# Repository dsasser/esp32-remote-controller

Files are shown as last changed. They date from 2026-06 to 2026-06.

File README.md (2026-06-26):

# ESP32-S3 4-Channel Remote Igniter Controller

A portable, wireless 4-channel remote igniter controller for **hobby rocketry**. Fires up to four Estes-type igniters independently over BLE from a phone. Single 2S Li-ion battery, ESP32-S3 Super Mini, in a Hammond 1455N1601BK anodized aluminum enclosure with custom SendCutSend panels.

> **Status:** Hardware design finalized (2S single-battery). Firmware in active development.

Assembled controller

Schematic

---

## Features

- 4 independently fired channels for hobby igniters
- 7.4V raw cell voltage fires Estes igniters directly (0.5-1A typical)
- BLE 5.0 control via phone (WiFi / ESP-NOW options in firmware)
- Single 2S pack: 2x Samsung 30Q 18650 + 2S BMS
- One MP1584EN buck (7.4V -> 5V) for ESP32 and relay logic
- VNFOCKQSH optocoupler-isolated relay, mounted off-board
- TVS diode protection per channel; inline 5A fuse on the 7.4V rail
- Master power switch (SW1) cuts battery+ to the whole device
- 8.4V barrel-jack charging through the BMS (works with the switch off)
- Hammond aluminum enclosure with custom SendCutSend panels
- Socketed ESP32 and off-board relay — fully serviceable

---

## Quick Start

1. Order parts from the [Bill of Materials](docs/02-bom.md)
2. Review the [Schematic](docs/03-schematic.md)
3. Build following the [Assembly Guide](docs/07-assembly.md)
4. Flash firmware from the [Firmware Guide](docs/06-firmware.md)
5. Panels are pre-cut from the DXF files in [`/hardware`](hardware)

---

## Repository Structure

```
remote-controller/
├── README.md
├── LICENSE                    CERN-OHL-P (hardware) + MIT (firmware)
├── docs/
│   ├── 01-overview.md         Architecture, design decisions, specs
│   ├── 02-bom.md              Full bill of materials
│   ├── 03-schematic.md        Schematic + wiring (see images/schematic.svg)
│   ├── 04-pcb-layout.md       ElectroCookie breadboard-node placement
│   ├── 05-enclosure.md        Hammond enclosure + panel compatibility
│   ├── 06-firmware.md         BLE firmware, flashing, testing
│   ├── 07-assembly.md         Stage-by-stage build
│   └── images/
│       ├── schematic.svg          Block / interconnect schematic
│       ├── schematic-detail.svg   Component-level engineering schematic
│       ├── assembled.svg          Assembled three-quarter render
│       ├── parts-breakout.svg     Labelled parts breakout
│       ├── front-panel.svg        True-to-scale front panel elevation
│       └── rear-panel.svg         True-to-scale rear panel elevation
├── hardware/
│   ├── front_panel.dxf        Binding posts + LED (2D, aluminum)
│   ├── rear_panel.dxf         Power switch + charge jack + USB-C (2D, aluminum)
│   ├── front_panel.step/.stl  3D-print solid (Fusion / slicer)
│   ├── rear_panel.step/.stl   3D-print solid (Fusion / slicer)
│   └── generate_panels.py     Parametric source (CadQuery → STEP/STL)
└── firmware/
    └── remote_controller/
        └── remote_controller.ino
```

---

## Architecture at a Glance

```
[2S Pack 7.4V] -> [BMS] -> [SW1] -+-> [5A fuse] -> relay COM x4 -> NO -> [TVS] -> posts -> igniters
                                  |
                                  +-> [MP1584EN 5V] -> ESP32-S3 + relay logic
                                                |
                                          BLE <- phone
```

---

## Drawings & Renders

| Drawing | Description |
|---|---|
| [Assembled render](docs/images/assembled.svg) | Three-quarter view of the finished controller |
| [Parts breakout](docs/images/parts-breakout.svg) | Every component, grouped by function |
| [Component schematic](docs/images/schematic-detail.svg) | Net-level schematic for build / debug |
| [Front panel](docs/images/front-panel.svg) · [Rear panel](docs/images/rear-panel.svg) | True-to-scale elevations generated from the `/hardware` DXFs |
| [Internal layout](docs/images/internal-layout.svg) · [Side view](docs/images/internal-side.svg) | Top-down placement + connections, and heights/clearance |
| [PCB placement](docs/images/pcb-placement.svg) | Component placement on the ElectroCookie breadboard nodes |

---

## License

Hardware & docs: **CERN-OHL-P v2**. Firmware: **MIT**. See [LICENSE](LICENSE).

---

## Contributing

Issues and PRs welcome. If you build one, share photos — open an issue tagged `build-log`.

---

## Safety

This device fires pyrotechnic igniters. Relays default open at power-up; the firmware fires momentary pulses only. Follow NAR/Tripoli safety guidelines and maintain safe distance.

---

## Acknowledgements

Designed with assistance from Claude (Anthropic).

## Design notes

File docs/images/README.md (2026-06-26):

# Images

| File | What it is |
|---|---|
| `schematic.svg` | Block / interconnect schematic (2S single-battery) |
| `schematic-detail.svg` | Component-level engineering schematic — symbols, pins, rails, decoupling, per-channel TVS |
| `assembled.svg` | Three-quarter render of the finished controller |
| `parts-breakout.svg` | Every component, grouped by function with ref designators |
| `front-panel.svg` | True-to-scale front panel elevation (generated from `hardware/front_panel.dxf`) |
| `rear-panel.svg` | True-to-scale rear panel elevation (generated from `hardware/rear_panel.dxf`) |
| `internal-layout.svg` | Top-down floor plan — board/battery placement, connections, wire gauges |
| `internal-side.svg` | Side view — component heights, lid clearance, wire-gauge table |
| `pcb-placement.svg` | PCB component placement on the ElectroCookie breadboard nodes |

The two panel elevations are generated from the DXF source; if the DXFs change, regenerate rather than hand-editing the SVG.

Add build photos here as the hardware comes together.

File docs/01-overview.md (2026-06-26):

# 01 — System Overview

## What This Is

A portable 4-channel remote igniter controller for **hobby rocketry**. It fires up to four Estes-type igniters wirelessly over BLE from a phone, delivering a momentary firing pulse to each channel independently. Built around the ESP32-S3 Super Mini in a Hammond 1455N1601BK anodized aluminum enclosure with custom SendCutSend panels.

---

## Design Goals

| Goal | How it's met |
|---|---|
| Portable and self-contained | Single internal 2S battery, no external power |
| Wireless control | ESP32-S3 BLE 5.0, ~30-100ft range |
| Safe firing | Relays default open, optocoupler isolation, TVS protection |
| Simple | One battery, one buck converter, minimal parts |
| Serviceable | Socketed ESP32, off-board relay, replaceable inline fuse |
| Professional finish | Hammond aluminum enclosure, SendCutSend panels |

---

## System Architecture

A single **2S Li-ion pack** (2× Samsung 30Q in series, 7.4V nominal) powers everything:

- **Firing power:** Raw 7.4V routes through the master switch (SW1) and a 5A fuse to the relay COM terminals. When a relay fires, 7.4V appears across the binding posts and fires the igniter. Estes igniters need only 0.5-1A, so 7.4V is entirely sufficient. With SW1 off, the COM bus and posts are dead.
- **Logic power:** One MP1584EN buck converter steps 7.4V down to a regulated 5.0V, powering both the ESP32-S3 and the relay module's coil/logic side.

This single-battery design replaced an earlier, more complex dual-battery architecture. The simplification was possible because hobby igniters are forgiving, low-current loads.

```
[Phone / BLE]
      | BLE
      v
[ESP32-S3 Super Mini] --GPIO4-7 via 6-wire ribbon--> [VNFOCKQSH Relay (off-board)]
      ^                                                      |
[MP1584EN 5V buck]                                      COM x4 <-- 7.4V (switched, fused)
      ^                                                NO x4
[SW1 master power switch]                                   |
      ^                                              [TVS D2-D5] + [Binding Posts]
[2S Pack: 2x Samsung 30Q] -> [2S BMS] <-- 8.4V charger      |
                                                      [Igniters 1-4]
```

---

## Key Design Decisions

**Why 2S 18650 instead of a 12V pack?**
Estes igniters fire at 0.5-1A. The raw 7.4V from two series cells drives them directly — no need for a 12V switching supply or a separate logic battery. Two cells, one BMS, one buck converter. Lighter and simpler.

**Why the VNFOCKQSH relay module?**
Cheaper and faster-shipping than the original pick, with optocoupler isolation and a selectable H/L trigger jumper. The optocouplers protect the ESP32 GPIOs; the relay contacts handle output isolation. The JD-VCC jumper is removed.

**Why mount the relay off-board?**
Keeps the ElectroCookie PCB compact and uncluttered. The relay bolts to the Hammond's internal floor via M3 screws and connects back to the board with a 6-wire ribbon (GND, 5V, IN1-4). Easy to replace.

**Why BLE?**
No infrastructure needed — works anywhere at the launch site. Pairs in under a second. The firmware also has WiFi and ESP-NOW options roughed in.

---

## Specifications

| Parameter | Value |
|---|---|
| Output channels | 4 |
| Output voltage | 7.4V (raw 2S cell voltage) |
| Igniter load | 0.5-1A typical (Estes-type) |
| Pulse duration | Configurable, default 1000ms |
| Wireless | BLE 5.0 (primary), WiFi / ESP-NOW (optional) |
| Battery | 2S — 2x Samsung 30Q 18650, 7.4V ~3000mAh |
| BMS | 2S Li-ion protection, 10A+ |
| Charging | 8.4V wall charger via DaierTek barrel jack |
| Output connectors | 4mm banana binding posts, 4 pairs |
| Enclosure | Hammond 1455N1601BK, 160x103x53mm |
| Microcontroller | ESP32-S3 Super Mini |
| Relay | VNFOCKQSH 5V 4-channel, optocoupler isolated |
| Protection | TVS diodes, optocoupler isolation, 5A fuse, 2S BMS |

---

## Safety Notes

This device fires pyrotechnic igniters. Observe standard rocketry safety:

- Relays default to open (safe) on power-up
- Keep the system unpowered until ready to fire
- Maintain safe distance per NAR/Tripoli guidelines
- The momentary-pulse firmware prevents a stuck-on output
- TVS diodes clamp inductive spikes from the igniter bridgewire

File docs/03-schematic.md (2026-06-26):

# 03 — Schematic

Schematic

The block-level schematic above (`docs/images/schematic.svg`) documents interconnection between the modules.

For a net-level view an electronics engineer can build and debug from — proper symbols, pin names, power rails, decoupling, per-channel TVS and binding posts — see the component schematic:

Component schematic

---

## Power Architecture

A single 2S pack feeds two paths:

```
[2S Pack: 2x Samsung 30Q in series, 7.4V]
        |
   [2S BMS] <--- 8.4V charger (DaierTek barrel jack J1)
        |
   [SW1 master power]  --lamp--> GND   (illuminated rocker, rear panel)
        |
   [F1 5A inline fuse]
        |
   7.4V BUS ----+---------------------------+
        |       |                           |
        |   relay COM x4              [MP1584EN U1]
        |                             7.4V -> 5.0V
        |                                   |
        |                              5V BUS
        |                                   |
        |                          +--------+--------+
        |                       [ESP32-S3]      [Relay VCC]
        v
   relay NO x4 --> [TVS D2-D5] --> [Binding posts] --> igniters
```

GND is common across the whole system. **SW1 sits between the BMS and the
7.4V bus**, so when it's off the ESP32, the buck, and the firing rail (relay
COM and the binding posts) are all de-energized. The charger feeds the BMS
*upstream* of SW1, so the pack still charges with the device switched off.

---

## Designators

| Ref | Component |
|-----|---|
| B1 | 2S pack — 2x Samsung 30Q 18650 in series (7.4V) |
| — | 2S Li-ion BMS protection board |
| J1 | DaierTek 5.5x2.1mm barrel jack (charge port) |
| SW1 | Master power rocker switch (illuminated, ∅12mm panel-mount) |
| F1 | 5A blade fuse + inline holder (internal) |
| U1 | MP1584EN buck converter (7.4V -> 5.0V) |
| U2 | ESP32-S3 Super Mini |
| K1 | VNFOCKQSH 4-channel relay module (off-board) |
| D1 | 5mm green LED (status) |
| R1 | 330Ω ¼W resistor |
| D2-D5 | P6KE15A TVS diodes (one per channel) |
| C1 | 100µF 25V electrolytic (5V decoupling) |
| C2-C5 | 0.1µF ceramic (relay IN decoupling) |
| BT1-BT4 | 4mm banana binding post pairs |

---

## GPIO Assignments

| GPIO | Function |
|---|---|
| GPIO4 | Relay IN1 (Channel 1) |
| GPIO5 | Relay IN2 (Channel 2) |
| GPIO6 | Relay IN3 (Channel 3) |
| GPIO7 | Relay IN4 (Channel 4) |
| GPIO2 | Status LED (via R1) |

---

## Relay Connection (6-wire ribbon)

The relay module mounts off-board on the enclosure floor. A 6-conductor ribbon connects it to screw terminals on the PCB:

| Ribbon wire | From (PCB) | To (relay) |
|---|---|---|
| 1 | GND bus | GND |
| 2 | 5V bus | VCC |
| 3 | GPIO4 | IN1 |
| 4 | GPIO5 | IN2 |
| 5 | GPIO6 | IN3 |
| 6 | GPIO7 | IN4 |

Relay COM terminals connect to the fused 7.4V bus. Relay NO terminals go to the TVS diodes and binding posts.

---

## Critical Notes

### MP1584EN pre-adjustment
Before connecting the ESP32 or relay, power the MP1584EN from the pack and adjust its trimmer pot until the output reads **5.00V ± 0.05V**. The pot is sensitive — use a small flat screwdriver and turn slowly. Over-voltage damages the ESP32-S3.

### Relay jumpers
- **JD-VCC jumper: removed.** The optocouplers already isolate the ESP32 GPIOs; output isolation is handled by the relay contacts.
- **H/L trigger jumper: set to match firmware.** The VNFOCKQSH has a selectable high/low trigger. Set it to match the firmware's `RELAY_ACTIVE_LOW` setting (default active-LOW).

### TVS orientation
P6KE15A is unidirectional. The **cathode (stripe end)** faces the positive binding post. Reversed orientation shorts the output.

### Master switch (SW1) & lamp
SW1 carries the full battery+ current (logic plus firing — a few amps peak), so use a switch rated comfortably above that; the linked rocker is rated well beyond. Wire the two contact leads in series with battery+ (BMS out → SW1 → F1). The two lamp leads are a separate illuminated indicator: lamp+ to the switched 7.4V (downstream of SW1), lamp− to GND, so it glows when the device is on. **If the lamp is rated 12V it will be dim or dark at 7.4V** — the switching itself is unaffected; for a bright indicator either source the lamp from a 12V supply or rely on the front status LED.

### Wire gauge
- 18 AWG for all 7.4V power (battery, switch, fuse, COM, output)
- 22 AWG for 5V logic and GPIO ribbon

---

## Why 7.4V Is Enough

Estes igniters fire at 0.5-1A. At 7.4V through a low-resistance bridgewire, the available current far exceeds the firing threshold. There is no benefit to a higher switching voltage for this load, which is what allowed the design to collapse from two batteries to one.

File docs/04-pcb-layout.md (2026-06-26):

# 04 — PCB Layout

The build uses a **black ElectroCookie solderable breadboard**. The medium (~80×60mm, 30-column) board is enough — the layout below uses only ~22 of its 30 columns — but a larger ElectroCookie also fits the enclosure if you want more elbow room. The relay module mounts **off-board** on the enclosure floor, so the PCB only carries the ESP32, buck, decoupling, the TVS/output section, and the screw terminals.

PCB placement on the breadboard nodes

---

## Work with the copper, not against it

The ElectroCookie is a 1:1 breadboard replica, so component placement follows breadboard rules — it is **not** free-form:

- **Node strips:** the main field is two banks split by a **center gap**. Each vertical group of **5 holes is one electrical node** (one trace). Adjacent groups are isolated.
- **Power rails:** continuous bus strips run along the two **long edges**. Dedicate one rail to **+5V** and the other to **GND**. (If your board has a second rail per side, give the spare to **+7.4V** and skip the jumper below.)

The consequence: a part with two rows of pins (notably the ESP32-S3) **straddles the center gap**, so each pin lands on its own 5-hole node with four free holes for jumpers — exactly like seating a DIP on a breadboard. Small single-row modules (the MP1584EN) just sit in one bank, each pad on its own node.

---

## Placement

### Power rails (long edges)
- Top edge → **+5V** bus. Bottom edge → **GND** bus.
- Jumper each part's 5V and GND pins straight to the nearest rail.
- **7.4V** has no dedicated rail on a 2-rail board: bring it in on a screw terminal and jumper it to the MP1584EN input and the relay-COM feed. (Or use a 3rd/4th rail if your board has one.)

### MP1584EN buck — input end
- Each pad on its own node. **IN+** from the 7.4V terminal, **IN−/OUT−** to the GND rail, **OUT+** jumpered to the +5V rail.
- **Mount and trim to 5.00V before anything else is connected.** The pot is sensitive.

### ESP32-S3 Super Mini — center, straddling the gap
- On two rows of **8-pin female 2.54mm headers** (the Super Mini is narrow). Socketed so it lifts out.
- 5V pin → +5V rail; GND → GND rail.
- **GPIO4–7** jumper to the relay-signal screw terminal (the 6-wire ribbon). **GPIO2 → R1 →** a ~15cm flying lead to the panel status LED.

### TVS + outputs — output end
- Per channel: the **relay NO** wire lands on a node; a **TVS diode (D2–D5)** bridges that node to the **GND rail**, cathode (stripe) toward the **+** output; an output screw terminal taps the same node out to the binding post **+**. Each post **−** returns to the GND rail.

### Decoupling
- **C1** (100µF) across +5V↔GND near the ESP32. **C2–C5** (0.1µF) at the relay IN terminals.

---

## Wire gauge

| Run | Gauge |
|-----|---|
| 7.4V firing path (battery, fuse, SW1, relay COM, NO → posts) | **18 AWG** |
| 6-wire ribbon to the relay (GND, 5V, IN1–IN4) | 18–22 AWG (logic/signal only, <0.4A) |
| 5V / GPIO logic, status-LED lead | 22–26 AWG |

Keep the 7.4V runs on one side of the board and 5V/signal on the other where you can, for noise isolation.

---

## Internal mounting

```
Hammond 1455N1601BK floor (single layer, ~20mm-tall parts, ~25mm headroom):
  - ElectroCookie PCB on M3 standoffs (front)
  - VNFOCKQSH relay module bolted flat to the floor, M3 (rear)
  - 2S 18650 pack lying down, hook-and-loop strap
  - 2S BMS + inline 5A fuse tucked beside the battery
  - SW1, barrel jack, USB-C on the rear panel; binding posts + LED on the front
```

See [07-assembly.md](07-assembly.md) for the top-down layout and side-view height drawings. The off-board relay and single battery leave plenty of room; the 6-wire ribbon has enough slack to lift the PCB out without unplugging the relay.

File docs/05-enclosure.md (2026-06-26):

# 05 — Enclosure

## Hammond 1455N1601BK

**External:** 160mm L x 103mm W x 53mm H
**Internal usable depth:** ~45mm
**Material:** Extruded aluminum, black anodized, IP54
**End panels:** Removable aluminum, 103 x 53mm each

Front and rear panels are custom-cut by **SendCutSend** from the DXF files in `/hardware`.

---

## Revision after first fabrication

The first set of panels came back from SendCutSend with three fit problems against the real parts:

1. **Binding-post nuts collided.** The two posts in each pair were only 10mm apart center-to-center; the mounting nuts/washers overlap and can't both seat.
2. **Fuse slot was unusable.** The 20×13mm slot assumed a panel-mount blade fuse holder, but the fuse in the BOM is an **inline pigtail holder** that has no flange or thread to mount through a panel at all.
3. **USB-C opening was too small.** The 9×3.5mm slot fit only a bare USB-C *plug*, not a panel-mount USB-C *receptacle*. It's now a **∅11.5mm round hole** for an M11×1.0 threaded receptacle (J2) whose nut clamps any panel thickness.

The DXFs in `/hardware` are the **corrected revision**:

| Panel feature | Size | Resolution |
|---|---|---|
| Front: 8× ∅8mm holes | 8mm | Binding posts re-laid as a **2-row grid** (4 columns @ 22mm pitch, +/− rows 20mm apart) so nuts clear — min 20mm center-to-center |
| Front: ∅5mm hole | 5mm | Status LED — moved to the right edge, vertically centered |
| Rear: ∅12mm round hole | 12mm | DaierTek barrel jack — unchanged, correct size |
| Rear: ~~20×13mm fuse slot~~ | — | **Removed.** Inline fuse holder now lives inside the enclosure |
| Rear: ∅12mm round hole | 12mm | **Master power switch (SW1)** restored — see note below |
| Rear: USB-C cutout | **∅11.5mm round** | M11×1.0 threaded panel-mount USB-C, nut-clamped (was 9×3.5mm) |
| Both: 4× ∅3mm corner holes | 3mm | M3 panel mounting — unchanged |

> The rear USB-C receptacle preserves wired firmware flashing and serial debug access to the ESP32-S3 Super Mini. It's an **M11×1.0 threaded mount**: the barrel passes through the ∅11.5mm hole and a hex nut clamps from behind, so it seats solidly in panels of any thickness. Its 4-wire pigtail plugs into the ESP's USB pads internally.

> **Master power switch (SW1) restored.** The original design had a panel master switch, but it was lost when the design consolidated to 2S — its rear slot was relabeled as the fuse cutout and then removed. It's back as a **∅12mm round hole at X=22mm**, giving a symmetric POWER / CHARGE / USB-C layout. A master cutoff is *more* important in the 2S design: the pack feeds the buck continuously, so without it the ESP32 is always drawing current, and switching it off de-energizes the firing rail (the binding posts go dead). See [03-schematic.md](03-schematic.md).

> The 5A fuse is now an **inline holder wired into the battery+ lead inside the box** (see [02-bom.md](02-bom.md)). The rear panel carries no fuse cutout. To restore panel-accessible fuse swaps, switch to a round-bezel panel-mount holder and add a ∅12mm hole to `rear_panel.dxf`.

---

## Panel Elevations

These elevations are generated directly from the `/hardware` DXF coordinates, so they are true to scale (1:1 in mm). `CUT` features are red, `ENGRAVE` labels blue, dimensions gray.

**Front panel** — 4 binding-post pairs (CH1–CH4) in a 2-row grid, status LED, 4× M3 corner holes:

Front panel elevation

**Rear panel** — power switch, charge jack, USB-C cutout, 4× M3 corner holes (no fuse slot):

Rear panel elevation

---

## Front Panel Hole Positions

Posts sit in two rows: **+ (red) at Y = 36.5mm**, **– (black) at Y = 16.5mm**. Each channel is one column.

| Channel | Hole | Column X | + row Y | – row Y |
|---|---|---|---|---|
| CH1 | ∅8mm | 18.5mm | 36.5mm | 16.5mm |
| CH2 | ∅8mm | 40.5mm | 36.5mm | 16.5mm |
| CH3 | ∅8mm | 62.5mm | 36.5mm | 16.5mm |
| CH4 | ∅8mm | 84.5mm | 36.5mm | 16.5mm |
| Status LED | ∅5mm | 94.0mm | — (Y = 26.5mm) | |

Column pitch: 22mm. Row spacing (+ to –): 20mm. Minimum nut clearance: 20mm center-to-center.

## Rear Panel Hole Positions (Y = 26.5mm center)

| Feature | Hole | X position |
|---|---|---|
| Power switch SW1 | ∅12mm | 22mm |
| Charge jack J1 | ∅12mm | 52mm |
| USB-C (J2, flashing) | ∅11.5mm round (M11 threaded mount) | 87mm |

---

## Fabrication Files

The panels can be **laser/waterjet cut from aluminum** (2D DXF) or **3D printed** (3D STEP/STL solids). Both come from one shared geometry definition, so the hole positions match.

**DXF (aluminum)** — `/hardware/front_panel.dxf` and `/hardware/rear_panel.dxf` carry *nominal* hole sizes across five layers:
- `CUT` (red) — holes and slots
- `ENGRAVE` (blue) — labels
- `OUTLINE` (black) — panel boundary, reference only
- `DIMENSION` (gray) — measurements, reference only
- `CENTERLINE` (green, dashed) — hole crosshairs, reference only

These import directly into SendCutSend, Front Panel Express, or any CAD/CAM tool.

**STEP / STL (3D print)** — `/hardware/front_panel.step` and `/hardware/rear_panel.step` are the panels as **solid bodies** with PETG-compensated holes and debossed labels. In **Autodesk Fusion**, bring the STEP in via **File → Open** (or upload it to the project) — it lands as a native, editable solid you can tweak with push/pull. The matching `.stl` files (`Insert → Insert Mesh`, or straight into a slicer) are ready to print as-is.

> **Changing thickness:** the solids are built by `/hardware/generate_panels.py` (CadQuery). Edit `THICKNESS` at the top and re-run (`pip install cadquery && python hardware/generate_panels.py`) to regenerate both STEP + STL. That script is the parametric source — easier than push/pulling the body in Fusion, though either works.

---

## 3D-Printed Panels

The STEP/STL solids default to a **2mm** panel. Pick thickness by how the panel attaches:

- **~1.5mm** to slide into the Hammond extrusion's grooves (matches the stock aluminum panel).
- **2–3mm** for a stiffer panel bolted on through the four M3 corner holes.

> Every panel-mount part here clamps with a nut or threaded body — binding posts, the rocker switch (SW1), barrel jack, and the **M11×1.0 threaded USB-C** (J2). They all seat in any printed thickness, so there's no thin-wall snap-fit to design around. The USB-C thread is ~14.5mm long, plenty for a 2–3mm panel.

### Hole tolerances

Baked into the STEP/STL solids for black PETG on a 0.4mm nozzle. If your printer runs tight, bump the radii in `generate_panels.py` and re-run.

| Feature | Nominal | Printed |
|---|---|---|
| M3 corner hole | ∅3.0mm | ∅3.2mm |
| Binding post | ∅8.0mm | ∅8.4mm |
| Status LED | ∅5.0mm | ∅5.2mm |
| Power switch / barrel jack | ∅12.0mm | ∅12.4mm |
| USB-C (M11 thread) | ∅11.5mm | ∅11.9mm |

### Print settings

| Setting | Value |
|---|---|
| Material | Black PETG |
| Layer height | 0.15mm |
| Infill | 40% |
| Orientation | Front (labeled) face down — best surface on the visible side |

---

## Panel Labeling

For now a label maker works fine. For a professional finish, the DXF `ENGRAVE` layer can be sent to SendCutSend (engraving) or Front Panel Express for laser-engraved, anodized labels.

Suggested labels: CH1-CH4 above each binding-post column, "CHARGE" by the barrel jack, "USB-C" by the rear USB cutout, polarity + / - marks per post. (The fuse is internal, so it needs no panel label.)

---

## Internal Mounting

- **PCB:** M3 standoffs to the floor, or slide into the enclosure's internal rails
- **Relay module:** bolted flat to the floor via M3 through its corner holes
- **2S pack:** hook-and-loop strap to the floor so it can't shift
- **Inline fuse holder:** wired into the battery+ lead and tucked inside the box (zip-tied to the floor or harness); open the enclosure to swap the fuse
- **Barrel jack + USB-C receptacle:** panel-mounted on the rear, wired with enough slack to swing the panel open ~45 deg for servicing

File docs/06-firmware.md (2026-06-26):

# 06 — Firmware

## Overview

The firmware runs on the ESP32-S3 Super Mini using the Arduino ESP32 core. It exposes a BLE GATT service with a single writable characteristic. Writing the values `"1"` through `"4"` fires the corresponding channel for the configured pulse duration.

The complete firmware source is in `/firmware/remote_controller/remote_controller.ino`.

---

## Development Environment Setup

### 1. Install Arduino IDE

Download from [arduino.cc/en/software](https://www.arduino.cc/en/software). Version 2.x recommended.

### 2. Add ESP32 Board Support

In Arduino IDE: **File → Preferences → Additional boards manager URLs**, add:

```
https://raw.githubusercontent.com/espressif/arduino-esp32/gh-pages/package_esp32_index.json
```

Then: **Tools → Board → Boards Manager**, search `esp32`, install **esp32 by Espressif Systems** (version 3.x recommended).

### 3. Select Board

**Tools → Board → ESP32 Arduino → ESP32S3 Dev Module**

Settings:
- USB Mode: **USB-OTG (TinyUSB)**
- Upload Mode: **UART0 / Hardware CDC**
- Flash Size: **4MB**
- Partition Scheme: **Default 4MB with spiffs**

### 4. Select Port

Plug the ESP32-S3 Super Mini in via USB-C. If no port appears, hold the BOOT button while plugging in. Select the corresponding port under **Tools → Port**.

---

## Flashing

With the board selected and port set, open `/firmware/remote_controller/remote_controller.ino` and click **Upload** (→ arrow). The IDE compiles and flashes. The status LED will blink 3 times then hold solid when BLE is advertising.

If the upload fails: hold BOOT on the ESP32-S3, press and release RESET, then release BOOT. This forces download mode.

---

## BLE Protocol

| Property | Value |
|---|---|
| Device name | `RemoteBox` |
| Service UUID | `4fafc201-1fb5-459e-8fcc-c5c9c331914b` |
| Characteristic UUID | `beb5483e-36e1-4688-b7f5-ea07361b26a8` |
| Characteristic property | WRITE |

### Commands

Write a single ASCII character to the characteristic:

| Value | Action |
|---|---|
| `"1"` | Fire channel 1 |
| `"2"` | Fire channel 2 |
| `"3"` | Fire channel 3 |
| `"4"` | Fire channel 4 |
| `"A"` | Fire all channels simultaneously |
| `"S"` | Status query (returns `"OK"` if connected) |

### Testing Without an App

Use **nRF Connect** (iOS / Android — free):

1. Open nRF Connect, tap **SCAN**
2. Find `RemoteBox` in the list, tap **CONNECT**
3. Navigate to the service UUID, expand the characteristic
4. Tap the **↑ Upload** icon to write
5. Type `1`, `2`, `3`, or `4`, tap **SEND**
6. You should hear the relay click

---

## LED Status Codes

| Pattern | Meaning |
|---|---|
| 3 blinks, then solid ON | BLE advertising, ready |
| Solid ON | BLE connected |
| OFF | Not powered / error |
| Fast blink (100ms) | Firing in progress |

---

## Configuration

At the top of `remote_controller.ino`, adjust these defines to customize behavior:

```cpp
// GPIO assignments — match your wiring
#define CH1_PIN   4
#define CH2_PIN   5
#define CH3_PIN   6
#define CH4_PIN   7
#define LED_PIN   2

// Pulse duration in milliseconds
#define FIRE_MS   1000

// BLE device name (appears in phone scan list)
#define BLE_NAME  "RemoteBox"

// Active LOW relay logic (true for most prebuilt relay modules)
// Set to false if your relay fires on HIGH.
// Match the VNFOCKQSH H/L trigger jumper to this setting.
#define RELAY_ACTIVE_LOW  true
```

---

## WiFi Alternative

If you prefer WiFi control over BLE, a web server approach is straightforward with the ESP32 Arduino core. The ESP32-S3 can host its own access point — no router needed. See the commented-out WiFi section at the bottom of the firmware file for a starting point.

WiFi adds ~1–2 seconds of connection time vs BLE's near-instant connection, but gives you a browser-based UI on any device.

---

## ESP-NOW Option (future)

For a dedicated physical button controller (a second ESP32-S3 as a handset), ESP-NOW provides:

- No pairing or handshake — just power on and it works
- Sub-10ms latency
- ~200m range
- Works without any phone

See the `firmware/esp_now_controller/` directory (planned — contributions welcome).

---

## Troubleshooting

| Problem | Likely cause | Fix |
|---|---|-----|
| Relay clicks but igniter doesn't fire | Pack low or 5A fuse blown | Check fuse F1 and pack charge |
| BLE not appearing in scan | Wrong board selected, or crash at boot | Check serial monitor at 115200 baud |
| All relays fire on boot | Relay active-HIGH logic mismatch | Set `RELAY_ACTIVE_LOW false` |
| Upload fails | ESP32-S3 not in download mode | Hold BOOT, tap RESET, release BOOT |
| LED stays off | Wrong LED pin or LED polarity | Check GPIO2 and LED orientation |
| MP1584EN output too high | Pot not pre-adjusted | Adjust to 5.00V before connecting |

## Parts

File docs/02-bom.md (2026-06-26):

# 02 — Bill of Materials

4-channel remote igniter controller for hobby rocketry. Single 2S Li-ion battery architecture. Prices are estimates as of mid-2026.

---

## Core Modules

| Ref | Component | Spec | Sourcing | Est. Price | Qty |
|-----|---|---|---|---|-----|
| U2 | ESP32-S3 Super Mini | BLE 5.0, WiFi, USB-C, compact | Amazon — "ESP32-S3 Super Mini" | ~$8 | 1 |
| K1 | VNFOCKQSH 4-channel relay module | 5V, optocoupler isolated, H/L trigger jumper, 10A contacts | Amazon — "VNFOCKQSH 4 channel relay 5V" | ~$8 | 1 |
| U1 | MP1584EN buck converter | Adjustable **step-down**, 7.4V → 5.0V, 3A | Amazon — "MP1584EN buck converter" | ~$8 (multi-pack) | 1 |
| J2 | Panel-mount USB-C pigtail | Female USB-C, **M11×1.0 threaded + hex nut** (∅13.8mm flange, **∅11mm round panel hole**, ~14.5mm thread clamps any panel thickness), 4-wire pigtail to ESP USB | Amazon — "M11 threaded panel mount USB-C" | ~$6 | 1 |

---

## Battery & Power

| Ref | Component | Spec | Sourcing | Est. Price | Qty |
|-----|---|---|---|---|-----|
| B1 | 18650 cells | Samsung 30Q 3000mAh, flat top — **2 in series** | [18650batterystore.com](https://www.18650batterystore.com) | ~$8 each (~$16) | 2 |
| — | 2S Li-ion BMS | 2S protection board, 10A+ | Amazon — "DIANN 2S BMS" | ~$6 | 1 |
| — | 2S charger | 8.4V wall charger, 5.5×2.1mm barrel plug | Amazon — "iCreatin 8.4V charger" | ~$10 | 1 |
| J1 | Charge jack | DaierTek panel-mount 5.5×2.1mm barrel jack | Amazon — "DaierTek panel mount barrel jack" | ~$8 (multi) | 1 |
| — | 18650 holder | 2-cell series holder or 2x single holders | Amazon | ~$6 | 1 |

> **Why 2S (7.4V)?** Estes hobby igniters fire reliably at 0.5-1A. The raw 7.4V cell voltage drives them directly through the relay contacts — no separate high-voltage switching supply needed. This single-battery architecture replaced an earlier dual-battery (12V LiFePO4 + 18650 logic) design, removing significant complexity.

> **Cell sourcing:** Buy Samsung 30Q from a reputable vendor like 18650batterystore.com or imrbatteries.com. Avoid Amazon cells claiming inflated capacities. Use flat-top cells for series holders.

> **Charging:** The 8.4V charger connects through the DaierTek barrel jack and charges the pack through the BMS. Single-port charging — no need to remove cells.

---

## Switching & Protection

| Ref | Component | Spec | Sourcing | Est. Price | Qty |
|-----|---|---|---|---|-----|
| SW1 | Master power switch | SPST illuminated rocker, 4-wire (2 contact + 2 lamp), **∅12mm round panel-mount** | Amazon — "12mm round rocker switch illuminated" | ~$8 (multi) | 1 |
| F1 | Inline blade fuse holder | 5A blade fuse, **inline holder with wire pigtails** (ATC/ATO) | Amazon — "inline blade fuse holder 12AWG" | ~$8 | 1 |
| D2–D5 | TVS diodes | P6KE15A, 600W 15V unidirectional, DO-15 axial | Amazon — "P6KE15A TVS diode" | ~$8 (20-pack) | 4 |

> **Master switch (SW1):** A ∅12mm illuminated rocker on the rear panel cuts battery+ between the BMS and the fuse, so the whole device — ESP32, buck, and the firing rail — powers down with one switch. The charger feeds the BMS upstream of SW1, so the pack still charges when off. Its lamp leads are separate (4-wire); note an illuminated rocker rated for 12V will glow dim or not at all on the 7.4V rail — see [03-schematic.md](03-schematic.md).

> **Fuse:** A 5A blade fuse protects the 7.4V rail. It lives on an **inline holder wired into the battery+ lead inside the enclosure** — the holder the project actually uses is an inline pigtail type and cannot be panel-mounted, so the rear panel no longer carries a fuse cutout. To swap the fuse, open the enclosure (or pop the rear panel). If panel-accessible fuse swaps are desired later, switch to a true round-bezel panel-mount holder and add a ∅12mm hole to the rear DXF.

---

## Output Connectors

| Ref | Component | Spec | Sourcing | Est. Price | Qty |
|-----|---|---|---|---|-----|
| BT1–BT4 | Banana binding post pairs | 4mm panel-mount, red + black | Amazon — "Glarks banana binding post" | ~$10 (multi) | 8 posts |

> Hobby igniters connect via alligator clip leads that clip directly onto the banana posts. Convention: red = positive, black = negative per channel.

> **Post spacing:** The first front panel cut spaced the two posts of a pair only 10mm apart and their mounting nuts collided. The revised DXF lays the 8 posts out as a **2-row grid** — four channel columns at 22mm pitch, red (+) on the top row and black (–) on the bottom row 20mm below — so no two nuts are closer than 20mm center-to-center. Verify against your posts' actual nut/washer OD before re-ordering; widen the rows if your hardware is larger than ~14mm across.

---

## PCB & Passives

| Ref | Component | Spec | Qty |
|-----|---|---|-----|
| — | ElectroCookie PCB | Medium black, ~80x60mm | 1 |
| R1 | Resistor | 330Ω ¼W | 1 |
| D1 | LED | 5mm green diffused | 1 |
| C1 | Electrolytic cap | 100µF 25V (5V bus decoupling) | 1 |
| C2–C5 | Ceramic cap | 0.1µF (relay IN decoupling) | 4 |
| — | Female pin headers | 2.54mm — socket the ESP32-S3 | 2 strips |
| — | Screw terminal blocks | 2-pin 3.5mm — power/signal/output | ~8 |
| — | Ribbon cable | 6-conductor, relay link | ~30cm |

---

## Enclosure

| Ref | Component | Spec | Sourcing | Est. Price |
|-----|---|---|---|---|
| ENC | Hammond 1455N1601BK | 160x103x53mm, black anodized aluminum, IP54 | Amazon B005S3MICW | ~$33 |
| — | Custom panels | Front + rear, SendCutSend (DXF revised after first cut) | DXF in `/hardware` | — |

> Front and rear aluminum panels are cut by SendCutSend using the DXF files in `/hardware`. The **first fabrication revealed three fit problems** — colliding binding-post nuts, a fuse slot for a holder that can't be panel-mounted, and a USB-C opening sized for a bare plug. The DXFs in `/hardware` are the **corrected revision**; see [05-enclosure.md](05-enclosure.md) for details.

---

## Total Estimated Cost

| Category | Est. Cost |
|---|---|
| Core modules (ESP32-S3, relay, MP1584EN, USB-C pigtail) | ~$30 |
| Battery & power (cells, BMS, charger, jack, holder) | ~$46 |
| Switching & protection (switch, fuse, TVS) | ~$24 |
| Output connectors | ~$10 |
| PCB & passives | ~$20 |
| Enclosure | ~$33 |
| **Total** | **~$163** |

*ElectroCookie PCB and custom panels using existing/already-fabricated stock.*

---

## Changes From Previous Revision

This BOM reflects the **single 2S battery** architecture. Removed from earlier designs:

- ~~12.8V LiFePO4 battery~~ -> replaced by 2S 18650 pack
- ~~Separate 18650 + TP4056 logic supply~~ -> one pack now feeds both via MP1584EN
- ~~LiFePO4 14.6V charger~~ -> replaced by 8.4V 2S charger
- ~~Second converter / dual-rail logic supply~~ -> single MP1584EN **buck** (7.4V → 5.0V step-down)

The result is lighter, simpler, cheaper, and fully sufficient for hobby igniter loads.

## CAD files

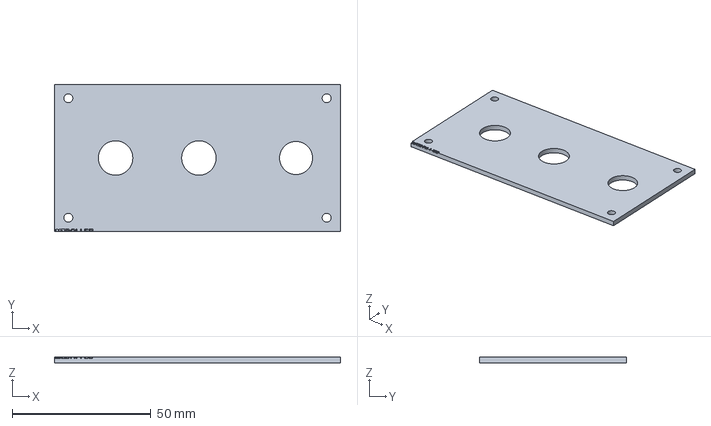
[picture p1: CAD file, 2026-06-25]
hardware/rear_panel.step
103.0 x 53.0 x 2.00 mm

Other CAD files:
hardware/front_panel.step
hardware/front_panel.dxf
hardware/front_panel.stl
hardware/rear_panel.dxf
hardware/rear_panel.stl

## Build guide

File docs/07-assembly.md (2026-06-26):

# 07 — Assembly Guide

Build in stages. Test each before moving on.

---

## Internal Layout

Where everything goes inside the Hammond enclosure — board placement, the 2S pack, the 6-wire ribbon, connectors, and wire gauges:

Top-down internal layout

Heights and lid clearance (everything sits in one layer):

Side view — heights and clearance

For component placement *on the PCB itself* (breadboard nodes, rails, where the ESP32/MP1584EN/TVS sit), see [04-pcb-layout.md](04-pcb-layout.md).

---

## Stage 1 — Battery Pack & BMS

1. Assemble the 2S pack: 2x Samsung 30Q in series in the holder (or series-wire two single holders)
2. Wire the pack to the 2S BMS: B+ / B- and the mid-point tap per the BMS markings
3. The BMS P+ / P- are the protected output (7.4V)
4. Verify pack voltage at P+ / P- with a multimeter — should read ~7.4-8.4V depending on charge

**Test:** ~7.4V present at BMS output, no heat, no spark on connection.

---

## Stage 2 — Charging Check

1. Wire the DaierTek barrel jack to the BMS charge input
2. Plug in the 8.4V charger
3. Confirm the pack charges (BMS LED or rising voltage toward 8.4V)

**Test:** Pack charges to 8.4V and the charger tapers off.

---

## Stage 3 — MP1584EN to 5.0V

1. Wire BMS output (7.4V) to MP1584EN IN+ / IN-
2. Power the MP1584EN, measure OUT+ / OUT-
3. **Adjust the trimmer pot until output reads 5.00V ± 0.05V.** Turn slowly.

**Test:** Stable 5.00V at MP1584EN output. Nothing downstream connected yet.

---

## Stage 4 — ESP32-S3 First Boot

1. Solder two 8-pin female header rows straddling the ElectroCookie center gap; plug in the ESP32-S3
2. Wire MP1584EN 5V -> +5V edge rail, GND -> GND edge rail
3. Flash a blink sketch over USB-C to confirm the toolchain
4. Flash the main firmware from `/firmware/remote_controller/`
5. Confirm `RemoteBox` appears in a BLE scan (nRF Connect)

**Test:** Phone sees `RemoteBox` over BLE.

---

## Stage 5 — Relay (off-board) Logic Test

1. Bolt the VNFOCKQSH relay to the enclosure floor (M3)
2. Confirm the JD-VCC jumper is removed and the H/L trigger jumper matches firmware (default active-LOW)
3. Run the 6-wire ribbon: GND, 5V, IN1->GPIO4, IN2->GPIO5, IN3->GPIO6, IN4->GPIO7
4. Power logic only (no 7.4V to COM yet)
5. From nRF Connect, write "1"-"4"

**Test:** Each relay clicks on the matching command; relay LEDs light.

---

## Stage 6 — Master Switch, Fuse & Firing Power

1. Wire **SW1** (rear-panel master switch) in the battery+ line: BMS P+ → SW1 → inline 5A fuse
2. Fused, switched 7.4V -> relay COM x4 (parallel to the bus)
3. Lamp leads of SW1: to the switched 7.4V and GND (illuminated rocker; dim at 7.4V if it's a 12V lamp)
4. Measure: 7.4V at COM with SW1 on, **0V at COM with SW1 off**, 5V rail unchanged

**Test:** Switch cuts COM power; both rails present when on, no interference.

---

## Stage 7 — Output Channels

For each channel:
1. TVS diode (D2-D5) across the output — cathode stripe to + post
2. Relay NO -> binding post + (red)
3. GND -> binding post - (black)

**Test:** With a relay fired, ~7.4V across the binding posts; 0V idle.

---

## Stage 8 — LED, Caps, Enclosure

1. C1 (100µF) across the 5V rail near the ESP32
2. C2-C5 (0.1µF) at each relay IN line
3. R1 + D1 LED on GPIO2 out to the front panel (15cm lead)
4. Mount binding posts, LED, SW1, USB-C receptacle, barrel jack to panels
5. Secure PCB, relay, 2S pack, and the inline fuse holder inside
6. Dress wiring, close panels

**Final test:**
- BLE connects
- All 4 channels fire and show 7.4V at the posts
- LED solid when connected, blinks on fire
- No abnormal heat after a few minutes

---

## Safety Checklist (igniters)

- [ ] 5A fuse installed; SW1 cuts COM power when off
- [ ] JD-VCC jumper removed; H/L trigger matches firmware
- [ ] MP1584EN verified at 5.00V
- [ ] TVS cathode to + post on every channel
- [ ] Relays confirmed open (safe) at power-up
- [ ] All terminals tug-tested
- [ ] No bare conductors near the aluminum enclosure
- [ ] Igniters connected last, system kept unpowered until ready to fire
- [ ] Safe distance per NAR/Tripoli guidelines

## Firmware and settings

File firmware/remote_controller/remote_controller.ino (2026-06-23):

/**
 * Remote Igniter Controller Firmware
 * ESP32-S3 Super Mini — 4-Channel BLE Igniter Controller (hobby rocketry)
 *
 * Single 2S Li-ion pack (7.4V). Raw 7.4V fires Estes-type igniters through
 * the relay contacts; MT3608 boosts 7.4V -> 5V for ESP32 + relay logic.
 *
 * BLE GATT Service with single writable characteristic.
 * Write "1"–"4" to fire channels, "A" for all, "S" for status.
 *
 * Relay: VNFOCKQSH 4-ch, optocoupler isolated. JD-VCC jumper removed.
 * Set the module's H/L trigger jumper to match RELAY_ACTIVE_LOW below.
 *
 * License: MIT
 * Repository: https://github.com/[your-username]/remote-controller
 */

#include <BLEDevice.h>
#include <BLEServer.h>
#include <BLEUtils.h>
#include <BLE2902.h>

// ─── Configuration ───────────────────────────────────────────────
#define CH1_PIN   4       // GPIO for relay channel 1
#define CH2_PIN   5       // GPIO for relay channel 2
#define CH3_PIN   6       // GPIO for relay channel 3
#define CH4_PIN   7       // GPIO for relay channel 4
#define LED_PIN   2       // GPIO for status LED

#define FIRE_MS   1000    // Pulse duration in milliseconds

#define BLE_NAME  "RemoteBox"   // Appears in BLE scan list

// Most prebuilt relay modules are active-LOW (LOW = relay ON)
// Set to false if your module fires on HIGH
#define RELAY_ACTIVE_LOW  true

// BLE UUIDs — generate your own at uuidgenerator.net if forking
#define SERVICE_UUID        "4fafc201-1fb5-459e-8fcc-c5c9c331914b"
#define CHARACTERISTIC_UUID "beb5483e-36e1-4688-b7f5-ea07361b26a8"
// ─────────────────────────────────────────────────────────────────

// Relay ON/OFF helpers that respect RELAY_ACTIVE_LOW
#define RELAY_ON  (RELAY_ACTIVE_LOW ? LOW  : HIGH)
#define RELAY_OFF (RELAY_ACTIVE_LOW ? HIGH : LOW)

const int CH_PINS[] = { CH1_PIN, CH2_PIN, CH3_PIN, CH4_PIN };
const int NUM_CHANNELS = 4;

BLEServer*         pServer         = nullptr;
BLECharacteristic* pCharacteristic = nullptr;
bool               deviceConnected = false;

// ─── Channel firing ───────────────────────────────────────────────

void fireChannel(int pin) {
  // Blink LED during firing
  digitalWrite(LED_PIN, LOW);
  digitalWrite(pin, RELAY_ON);
  delay(FIRE_MS);
  digitalWrite(pin, RELAY_OFF);
  // Restore LED to connected state
  digitalWrite(LED_PIN, deviceConnected ? HIGH : LOW);
}

void fireAll() {
  digitalWrite(LED_PIN, LOW);
  for (int i = 0; i < NUM_CHANNELS; i++) {
    digitalWrite(CH_PINS[i], RELAY_ON);
  }
  delay(FIRE_MS);
  for (int i = 0; i < NUM_CHANNELS; i++) {
    digitalWrite(CH_PINS[i], RELAY_OFF);
  }
  digitalWrite(LED_PIN, deviceConnected ? HIGH : LOW);
}

// ─── BLE callbacks ────────────────────────────────────────────────

class ServerCallbacks : public BLEServerCallbacks {
  void onConnect(BLEServer* pSvr) override {
    deviceConnected = true;
    digitalWrite(LED_PIN, HIGH);   // Solid = connected
    Serial.println("BLE client connected");
  }

  void onDisconnect(BLEServer* pSvr) override {
    deviceConnected = false;
    digitalWrite(LED_PIN, LOW);
    Serial.println("BLE client disconnected — restarting advertising");
    // Restart advertising so another device can connect
    BLEDevice::startAdvertising();
    blinkLED(3, 200);              // 3 blinks = advertising
  }
};

class CharCallbacks : public BLECharacteristicCallbacks {
  void onWrite(BLECharacteristic* pChar) override {
    String val = String(pChar->getValue().c_str());
    val.trim();
    Serial.print("Received command: ");
    Serial.println(val);

    if      (val == "1") fireChannel(CH1_PIN);
    else if (val == "2") fireChannel(CH2_PIN);
    else if (val == "3") fireChannel(CH3_PIN);
    else if (val == "4") fireChannel(CH4_PIN);
    else if (val == "A" || val == "a") fireAll();
    else if (val == "S" || val == "s") {
      // Status response — set characteristic value to "OK"
      pChar->setValue("OK");
      pChar->notify();
    }
    else {
      Serial.println("Unknown command — valid: 1 2 3 4 A S");
    }
  }
};

// ─── Helpers ──────────────────────────────────────────────────────

void blinkLED(int count, int ms) {
  for (int i = 0; i < count; i++) {
    digitalWrite(LED_PIN, HIGH);
    delay(ms);
    digitalWrite(LED_PIN, LOW);
    delay(ms);
  }
}

// ─── Setup ────────────────────────────────────────────────────────

void setup() {
  Serial.begin(115200);
  Serial.println("\nRemote Controller booting...");

  // Configure output pins
  for (int i = 0; i < NUM_CHANNELS; i++) {
    pinMode(CH_PINS[i], OUTPUT);
    digitalWrite(CH_PINS[i], RELAY_OFF);  // All relays OFF at boot
  }
  pinMode(LED_PIN, OUTPUT);
  digitalWrite(LED_PIN, LOW);

  // BLE setup
  BLEDevice::init(BLE_NAME);

  pServer = BLEDevice::createServer();
  pServer->setCallbacks(new ServerCallbacks());

  BLEService* pService = pServer->createService(SERVICE_UUID);

  pCharacteristic = pService->createCharacteristic(
    CHARACTERISTIC_UUID,
    BLECharacteristic::PROPERTY_WRITE |
    BLECharacteristic::PROPERTY_NOTIFY
  );
  pCharacteristic->addDescriptor(new BLE2902());
  pCharacteristic->setCallbacks(new CharCallbacks());

  pService->start();

  BLEAdvertising* pAdvertising = BLEDevice::getAdvertising();
  pAdvertising->addServiceUUID(SERVICE_UUID);
  pAdvertising->setScanResponse(true);
  pAdvertising->setMinPreferred(0x06);
  BLEDevice::startAdvertising();

  Serial.println("BLE advertising as: " BLE_NAME);
  Serial.println("Service UUID: " SERVICE_UUID);
  Serial.println("Ready.");

  // 3 blinks = advertising and ready
  blinkLED(3, 200);
}

// ─── Loop ─────────────────────────────────────────────────────────

void loop() {
  // All work is done in BLE callbacks.
  // Keep loop empty or add watchdog logic here if needed.
  delay(100);
}

// ─── WiFi Alternative (commented out) ────────────────────────────
//
// Uncomment this block and comment out the BLE setup above to use
// WiFi with a simple web server instead. The ESP32-S3 hosts its own
// access point — no router needed.
//
// #include <WiFi.h>
// #include <WebServer.h>
//
// const char* AP_SSID = "RemoteBox";
// const char* AP_PASS = "12345678";   // min 8 chars for WPA2
// WebServer server(80);
//
// void handleRoot() {
//   server.send(200, "text/html",
//     "<h2>Remote Controller</h2>"
//     "<button onclick=\"fetch('/fire?ch=1')\">CH1</button>"
//     "<button onclick=\"fetch('/fire?ch=2')\">CH2</button>"
//     "<button onclick=\"fetch('/fire?ch=3')\">CH3</button>"
//     "<button onclick=\"fetch('/fire?ch=4')\">CH4</button>"
//   );
// }
//
// void handleFire() {
//   int ch = server.arg("ch").toInt();
//   if (ch >= 1 && ch <= 4) {
//     fireChannel(CH_PINS[ch - 1]);
//     server.send(200, "text/plain", "OK");
//   } else {
//     server.send(400, "text/plain", "Invalid channel");
//   }
// }
//
// // In setup():
// // WiFi.softAP(AP_SSID, AP_PASS);
// // server.on("/", handleRoot);
// // server.on("/fire", handleFire);
// // server.begin();
//
// // In loop():
// // server.handleClient();

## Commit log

2026-06-09 Initial commit.
    [front_panel.dxf, rear_panel.dxf]
2026-06-09 Add 3D print tolerances and settings to enclosure docs
    Documents hole radii for PETG printing (M3, button, LED, barrel jack)
    and rectangular cutout clearances, plus recommended print settings
    (black PETG, 0.15mm layers, 40% infill, top face down).
2026-06-09 Downgrade panel DXFs to AutoCAD R12 format for wider compatibility
    Re-exported front and rear panel files as AC1009 (R12) instead of
    AC1015 (2000) to maximize compatibility with laser/CNC cutting services.
    [front_panel.dxf, rear_panel.dxf]
2026-06-23 Changed name to remote-ignitor to better expain purpose.
    [front_panel.dxf, rear_panel.dxf]
2026-06-24 docs: add assembled render, parts breakout, panel elevations, and component schematic
    Add five SVG drawings and wire them into the docs:
    - assembled.svg three-quarter render of the finished controller
    - parts-breakout.svg every component grouped by function with ref designators
    - schematic-detail.svg net-level engineering schematic (symbols, pins, rails,
    C1/C2-C5 decoupling, GPIO4-7->IN1-4 ribbon, per-channel
    TVS with cathode stripe to the + post, binding posts)
    - front-panel.svg / rear-panel.svg true-to-scale (1:1 mm) panel elevations
    generated directly from the /hardware DXF coordinates,
    ma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
2026-06-25 Fix panel fit issues from first fab; add 3D-print solids
    The first SendCutSend panels had three fit problems against the real
    parts. Correct the geometry and propagate through DXFs, elevations, docs,
    and a new 3D-print pipeline.
    Panels:
    - Front: re-lay the 8 binding posts as a 2-row grid (4 channel columns at
    22mm pitch, +/- rows 20mm apart) so nut hardware clears — min 20mm
    center-to-center, was 10mm. Relocate the status LED.
    - Rear: remove the fuse slot (the BOM fuse is an inline pigtail holder,
    now mounted internally) and replace the bare-plug USB slot with a round
    hole for an M11x1.0 threaded panel-mount USB-C that clamps any
    thickness (was a snap-in cutout).
    3D printing (A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
    [front_panel.dxf, front_panel.step, front_panel.stl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]
2026-06-25 Restore master power switch (SW1) on the rear panel
    The master switch from the original design was lost during the 2S
    consolidation — its rear slot was relabeled as the fuse cutout, then
    removed with the fuse. Restore it: a master cutoff matters more in the 2S
    design, since the pack feeds the boost continuously and switching off also
    de-energizes the firing rail (dead binding posts).
    - Rear panel: add a ∅12mm hole for SW1 at X=22mm (POWER / CHARGE / USB-C
    layout). Regenerate DXF, elevation SVG, and STEP/STL solid.
    - Schematic: SW1 in series on battery+ between BMS and fuse; update both
    the block and component schematic figures; fix a stale panel-mount fuse
    label. Add designator, w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
    [rear_panel.dxf, rear_panel.step, rear_panel.stl]
2026-06-26 docs: add internal layout, side-view, and PCB node-placement diagrams
    Add three assembly visuals and wire them into the docs:
    - internal-layout.svg: top-down floor plan — PCB, relay, 2S pack, BMS
    placement, the 6-wire ribbon, the 7.4V path through fuse + SW1, outputs
    to the binding posts, rear connectors, and wire-gauge tags.
    - internal-side.svg: side elevation with component heights (~20mm parts,
    ~25mm headroom in the 45mm usable interior) and a wire-gauge table.
    - pcb-placement.svg: component placement on the ElectroCookie breadboard
    nodes (5-hole node strips, edge power rails, ICs straddling the gap).
    Rewrite 04-pcb-layout.md to be node-aware (the old "three zones" was a
    funct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
2026-06-26 Fix DC-DC: MT3608 boost → MP1584EN buck (step-down to 5V)
    A boost converter can't produce 5V from the 2S pack's 6–8.4V — that needs
    a step-down. The MT3608 (boost) was correct only for the earlier 3.7V
    single-cell logic supply and was left in by mistake when the design
    consolidated to one 2S pack. Swap U1 to an MP1584EN buck across the BOM,
    both schematics, the PCB/assembly/overview docs, and the figure labels.
